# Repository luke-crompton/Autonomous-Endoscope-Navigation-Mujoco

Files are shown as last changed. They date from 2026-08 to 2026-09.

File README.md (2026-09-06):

# Autonomous Colonoscope Navigation

**A reinforcement learning system that drives a flexible endoscope through a colon on its own,
using nothing but the view from its own tip camera.**

> **⚠️ Work in progress.** This is an active research project — the code, results, and
> documentation are all still changing. Treat everything here as provisional, and see
> [docs/CURRENT_PLAN.md](docs/CURRENT_PLAN.md) for where it actually stands right now.

https://github.com/user-attachments/assets/b2985821-82e3-45b8-a4c3-d8f6d5c38c22

*The full closed loop — one episode, ~30 s, no cuts. The trained policy steers itself through a
procedurally generated colon on nothing but what it can see.
**Left:** ground-truth depth, the DA3 depth estimate the policy is actually given, and the error
between them. **Centre:** the tip camera (a Blender render of the colon mesh). **Right:** a
third-person view of the 44-link flexible shaft bending and buckling against the wall as it is
pushed in. Perception runs on a Windows GPU; the policy checkpoint runs in WSL2. Nothing is
privileged and nothing is scripted.*

---

## What this is

Colonoscopy is hard to automate because the scope is a floppy tube: you push at one end and the
tip goes where the anatomy lets it. This project trains a policy to do the whole job in
simulation — steer the articulating tip **and** decide how fast to insert — from a monocular
depth image and a handful of proprioceptive scalars. No trajectory is prescribed and the
policy is never told where the lumen is; it has to infer that from what it can see.

The simulator models the scope as a real physical object: a 44-link flexible shaft fed by an
entrance roller mechanism, with a 25-hinge tendon-driven tip. Push force has to travel around
bends through wall contact, so **buckling, slip and getting stuck are genuine failure modes**
rather than things the model is protected from.

Every design decision is constrained by one rule: **the policy may only observe signals a real
rig can actually supply.** There is no force, tension, motor-current or ground-truth pose
anywhere in the observation.

| | |
|---|---|
| **Sees** | one 54×96 depth image (16:9, 100° horizontal FOV) + 6 scalars — the policy's own previous action, its internal filter state, and a binary tip-contact flag |
| **Does** | 3 continuous outputs in [-1, 1] — two cable-pair bend setpoints and one insertion feed rate |
| **At** | 25 Hz, matching the deployment rate the real depth model can sustain |
| **Trained by** | recurrent PPO (Sample Factory APPO) on procedurally generated colons |

---

## Status

**In real-hardware bring-up.** Simulation work is complete for this phase; the next milestone is
a physical rig trial. Current plan and open questions:
[docs/CURRENT_PLAN.md](docs/CURRENT_PLAN.md).

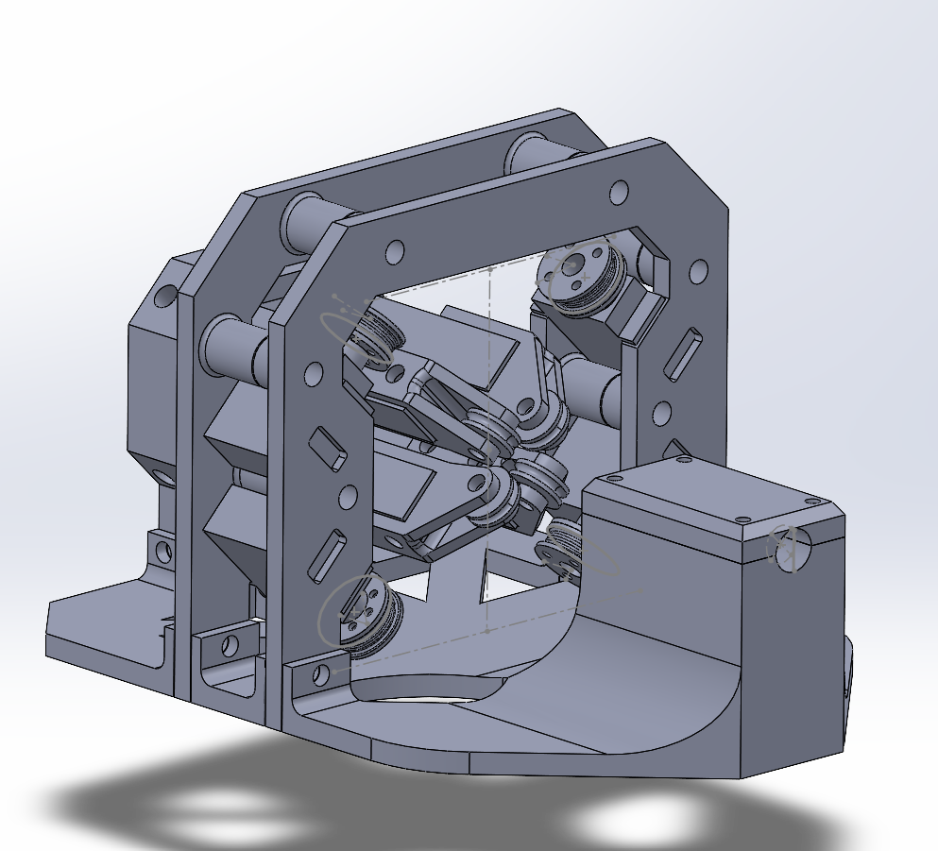
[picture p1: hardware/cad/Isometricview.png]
The tendon drive rig


*The tendon drive rig — four cables to two antagonistic pairs, driven by serial bus servos, with
a cantilever load cell on the shaft axis. [Open it in interactive 3D](hardware/cad/Full%20assem.STL).*

| Result | Value | Evidence |
|---|---|---|
| **v8_p1** (live line — physical shaft, 25 Hz, hardware-matching observation) | ~97% mean progress @ 4.52M steps | ⚠️ *training* statistic from sampled rollouts — **no evaluation run yet** |
| **v6_dr** (frozen milestone — kinematic base advance) | **93.75% completion, 96.7% mean progress** | benchmarked over 80 seeds × 5 episodes, [eval CSV included](navigation/v6_dr/runs_sf/v6_dr_700V3/) |
| Depth model (DA3-SMALL, fine-tuned) | 1.43 mm scale-aligned val MAE, vs 8.30 mm zero-shot | ⚠️ output is **scale-relative, not metric** — this is not a distance accuracy you can obtain at deploy |
| Depth throughput on the real camera | 31 fps / 32.18 ms | measured, `perception/realtime/bench_da3.py` |

The two lines are not directly comparable: v6_dr moved the scope base kinematically, while
v8_p1 has to physically push a flexible shaft. The completion metric also changed on
2026-07-13. **Mean progress is the honest axis** across versions.

---

## Where to go next

| If you want to know… | Read |
|---|---|
| How the whole system fits together | [docs/architecture.md](docs/architecture.md) — the three pipelines, the control loop, the network, the sim-to-real bridge |
| Why it is built this way, and what failed first | [docs/ITERATION_HISTORY.md](docs/ITERATION_HISTORY.md) — v1 → v8_p1, including the dead ends |
| The physical rig and what has to be measured | [hardware/README.md](hardware/README.md) — and [the assembly in interactive 3D](hardware/cad/Full%20assem.STL) |
| What happens next | [docs/CURRENT_PLAN.md](docs/CURRENT_PLAN.md) |
| Which RL version is which | [navigation/README.md](navigation/README.md) |
| How to run any of it | [docs/DEV_SETUP.md](docs/DEV_SETUP.md) |
| Everything else | [docs/README.md](docs/README.md) — full documentation index |

---

## Repository map

| Folder | What it is |
|---|---|
| `navigation/` | The RL system — environment, training, evaluation. Three lines: `v8_p1/` (**live**), `v7_shaft/` (superseded), `v6_dr/` (frozen milestone). See [navigation/README.md](navigation/README.md). |
| `perception/` | Monocular depth. `rd_v2/` is the DA3-SMALL fine-tune pipeline and error-map generator; `realtime/` is the live deployment runtime and camera tooling. |
| `simulation/` | Reference videoscope tip model. The navigation bundles carry their own copies by design. |
| `hardware/` | The physical rig — CAD, firmware, flex-PCB electronics, and bring-up measurements. See [hardware/README.md](hardware/README.md). |
| `docs/` | Documentation, iteration history, and archived training runs. |

Trained checkpoints are **not** in this repository — they exceed GitHub's file size limit and
are distributed as Release assets. `scenes/` folders are generated output and are always
regenerable.

---

## Attribution

The videoscope tip simulation (`generate_videoscope_one_section.py`, `new8.stl`) and the Blender
dataset-generation scripts used for depth fine-tuning were **provided by a research supervisor**,
and `colon_generator.py` is a port of the supervisor's generator. The navigation environment,
collision and contact modelling, reward design, domain randomisation, depth fine-tuning, the
sim-to-real error-map method, and all RL work are the author's own.

Licensed under the MIT License — see [LICENSE](LICENSE).

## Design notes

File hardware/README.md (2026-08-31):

# hardware/ — the physical rig

The real scope, the mechanism that drives it, and the measurements that decide whether the
trained policy transfers. This is where the project is now: simulation work for this phase is
complete and the next milestone is a physical rig trial.

> **⚠️ Work in progress.** The rig is still being built and nothing has been trialled yet.
> Insertion is **hand-fed for now** — the automatic feed drive is not built. The first
> policy-driven tests will run without it: the shaft is pushed in by hand so the **steering
> response** can be checked on its own before the feed mechanism is added.

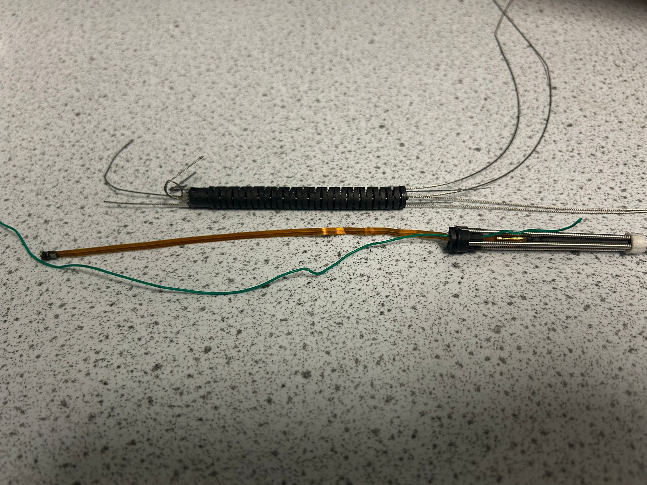
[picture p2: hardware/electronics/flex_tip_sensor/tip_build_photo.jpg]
The scope tip and its internals


*Two stages of the bending tip during assembly. Top: a bare articulating disk stack. Bottom: a
wired tip section — the flat orange ribbon is the camera cable, the four fine cables are the
steering tendons, and the coiled section is the tension spring. (The flex tip-contact sensor is
not fitted in this shot.)*

<table>
<tr>
<td>tip-to-shaft internals</td>
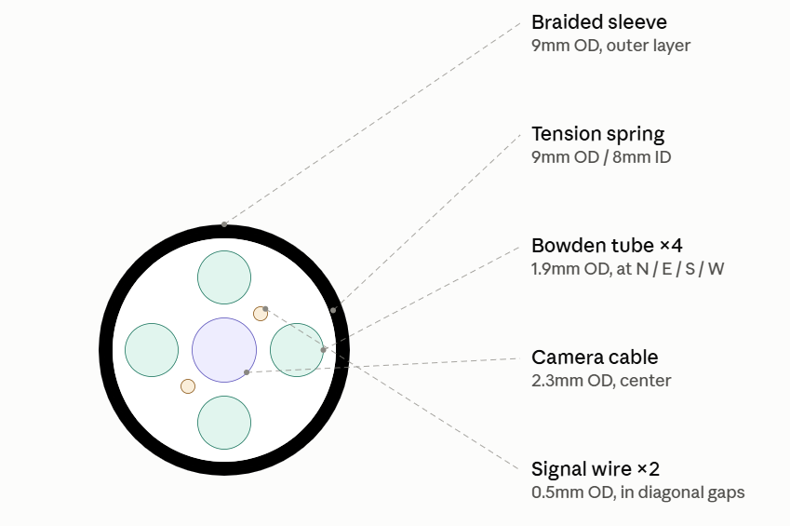
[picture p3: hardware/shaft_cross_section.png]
shaft cross-section
<td></td>
</tr>
</table>

*Left: the tip-to-shaft internals — the full shaft assembly end to end with the flexible spring
and braided housing removed. Right: the shaft cross-section — four tendon Bowden tubes at
N / E / S / W, the camera cable down the centre, and the two flex-sensor signal wires in the
diagonal gaps, all inside a tension spring and a braided sleeve. The tension spring provides a cylindrical shape and compression ridgitiy, and the braided sleeve provides the torsional ridgity to transmit rotation from the base to the tip. From testing the shaft internals provide enough bending resistance to stop buckling whilst still being flexible enough to navigate tight bends*

| Folder | What goes in it |
|---|---|
| [`cad/`](cad/) | SolidWorks sources for the scope, feeder and mounting, plus [`Full assem.STL`](cad/Full%20assem.STL) — **click it on GitHub for an interactive 3D view of the rig** |
| [`firmware/`](firmware/) | Arduino / microcontroller code driving the tendon motors and feed rollers |
| [`electronics/`](electronics/) | Flex PCBs. So far [`flex_tip_sensor/`](electronics/flex_tip_sensor/) — the tip-contact sensor (fabricated, not yet calibrated) |
| [`bringup/`](bringup/) | Test procedures, measurement scripts, and recorded results |

**Live camera and depth tooling is not here** — it lives in `perception/realtime/`
(`probe_camera.py`, `preview_camera_depth.py`, `bench_da3.py`). The dividing line: code that
processes images belongs to `perception/`, code that commands motors or reads encoders belongs
here. Procedures that exercise both go in `bringup/`.

---

## What the rig has to provide

These are requirements the simulator imposes — see [`../docs/architecture.md`](../docs/architecture.md)
for how the loop works, and the constants table at the end of this page for the exact numbers.
Nothing here describes measured hardware behaviour.

| | Requirement |
|---|---|
| **Rate** | one decision per 40 ms (25 Hz) |
| **Camera** | 16:9 frame; the policy was trained on 100° horizontal rectilinear |
| **Tendons** | 4 cables in 2 antagonistic pairs, **pull-only**, position-commanded to an absolute pull in mm |
| **Feed** | signed insertion rate, ±30 mm/s at full command — **hand-fed for now**, so `a[2]` is an operator advance/hold/withdraw cue, not yet a driven axis |
| **Contact** | a binary tip-contact flag — the only exogenous signal in the state vector besides the image. Hardware: [`electronics/flex_tip_sensor/`](electronics/flex_tip_sensor/), fabricated but not yet calibrated |
| **Software state** | the PD command shaper and previous-action echo must be **reproduced in software**, not measured — five of the six state floats are internal, not sensors |

---

## Status

**Not yet trialled.** Bring-up is in progress; see [`bringup/`](bringup/) for the pre-flight
measurements that have to happen before the first policy-driven run, and
[`../docs/CURRENT_PLAN.md`](../docs/CURRENT_PLAN.md) §7 for the authoritative sequencing.

The **tip-contact sensor now exists in hardware** — a polyimide flex electrode with a
piezoresistive film, [`electronics/flex_tip_sensor/`](electronics/flex_tip_sensor/) — but it is
uncalibrated and not yet wired in, so it does not change the status above.

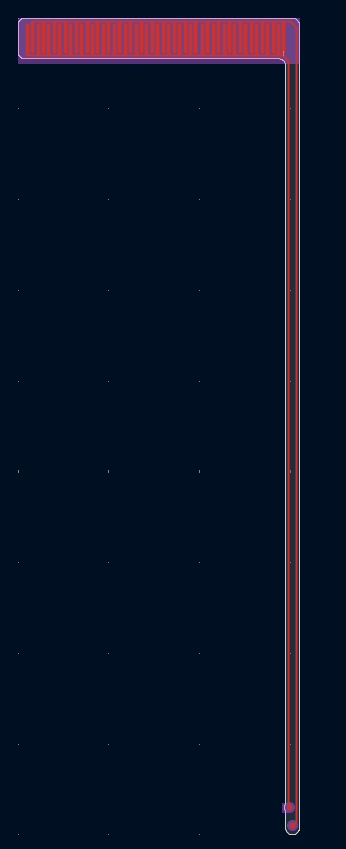
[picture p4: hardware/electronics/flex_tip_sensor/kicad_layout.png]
flex tip-contact sensor PCB layout


*Flex sensor PCB — comb head, 1.5 mm pigtail, solder pads. [Details](electronics/flex_tip_sensor/).*

Three sim-to-real gaps are known and quantified:

1. **Lens distortion.** The real camera is a **122° horizontal fisheye**; the pipeline was built
   on 100° horizontal rectilinear. Fix is perception-side only (measure `K`/`D`, then a
   precomputed `cv2.fisheye` undistort LUT applied before DA3) and is not a retrain blocker.
2. **`MAX_PULL_X` / `MAX_PULL_Z` are sim-derived** (6.795 / 7.361 mm). They normalise two of the
   six live policy inputs, so measuring them on the real scope is a correctness requirement, not
   an improvement.
3. **Camera roll offset is unmeasured.** In sim the tip camera is body-fixed and never rotates,
   so the image↔cable relationship is a constant. On the real scope that constant is unknown.
   The measurement procedure and what to do with the result are in [`bringup/`](bringup/) §2.

---

## Constants the deployment loop must reproduce

Read straight off `navigation/v8_p1/` (which is under version control). For the reward shape,
domain randomisation and episode logic — all training-only — see
[`../docs/architecture.md`](../docs/architecture.md).

| Quantity | Value | Note |
|---|---|---|
| Decision rate | **25 Hz** (40 ms) | 80 MuJoCo substeps × 0.5 ms in sim |
| `depth` observation | `(1, 54, 96)` float32, `[0, 1]` | normalise by **each frame's own maximum**, not a fixed metric clip — the obs is scale-relative |
| Camera field | **100.0° H × 67.7° V**, rectilinear, 16:9 | the sim camera and the DA3 fine-tune camera are the same camera by construction |
| `state` observation | `[cmd_x_n, cmd_y_n, last_action[0..2], tip_contact]` | 5 of 6 are software echo; only `tip_contact` is a sensor |
| `MAX_PULL_X` | 6.795 mm (X pair spans 12 joints) | ⚠️ from sim geometry — **measure on the real scope**, keep X and Z separate |
| `MAX_PULL_Z` | 7.361 mm (Z pair spans 13 joints) | ⚠️ same |
| PD command shaper | `PD_KP = 0.1803`, `PD_KD = 0.0475` | fitted at 25 Hz — **do not arithmetically rescale** for another rate (poles go unstable) |
| PD shaper response | τ = 214 ms, 95% settle 640 ms, 0% overshoot | its output is fed back as obs slots 0–1 — the filter is *inside* the observation loop |
| Action `a[0]`, `a[1]` | absolute pull setpoint `= a × MAX_PULL` | a position command, not a rate |
| Action `a[2]` | feed rate, full scale `1.2 mm/step = 30 mm/s` | accumulates into a monotonic insertion-depth target |
| Tendon force rail | **−10 N, pull-only** | cables cannot push |
| Policy output | take the Gaussian **mean**, not a sample | sampled σ ≈ 0.63; the mean cuts tip-command jitter ~91% |
| GRU hidden state | persists across steps, zeroed only at run start | re-instantiating the network per frame is not the trained policy |

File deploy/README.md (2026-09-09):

# deploy/ — the physical-rig control loop

The runtime stack that drives the real scope: **image → DA3 depth → APPO policy →
tendon setpoints → ESP32-S3**. Training / simulation lives in `navigation/`; this
directory is deployment only.

See `docs/architecture.md` ("The control loop") and `hardware/README.md`
("Constants the deployment loop must reproduce") for the contract, and
`docs/CURRENT_PLAN.md` §7 for where bring-up stands.

## Node graph

```
WINDOWS (no ROS, py3.11)          |  WSL2 UBUNTU (ROS 2 Humble)
camera idx 1 → DA3 → to_obs       |
  (1,54,96) f32, [0,1]            |
        │  TCP (TCP_NODELAY)      |
        └───────────────────────► depth_bridge ──/scope/depth───┐   sensor_msgs/Image 32FC1
                                                                 │
                                   /scope/telemetry ─────────────┤   scope_msgs/ScopeTelemetry
                                   /scope/estop (latched) ───────┤   std_msgs/Bool
                                   /scope/run_state (latched) ───┤   scope_msgs/ScopeRunState
                                                                 ▼
                                                          [ policy_node ]
                                                            APPO + GRU + PD command shaper
                                                                 │
                                                    /scope/action ▼   ScopeAction (normalised -1..1 per pair)
                                                          [ scope_link ] ──serial(COBS)──► ESP32-S3
                                                                 ▲                          runtime firmware
                                                                 └── /scope/telemetry, /scope/estop
```

No fisheye undistort — the 122°/100° lens gap is a known, accepted transfer risk
(`CURRENT_PLAN.md` §8). Insertion is hand-fed, so the policy's feed action never
reaches the motors; `policy_node` consumes it only as observation echo.

The steering command on the wire is **normalised** (±1 = full commanded bend).
The PD shaper runs normalised too — exactly matching the sim's `cmd / MAX_PULL`,
so nothing ROS-side needs `MAX_PULL`. The real per-axis-per-direction encoder
limits are **asymmetric** (measured: x +724/−681, z +840/−603 ticks —
`hardware/bringup/measured_constants.md`) and live only in the firmware, pushed
from `scope_params.yaml` via the `CONFIG` frame.

## Layout

| Path | State |
|---|---|
| `ros2_ws/src/scope_msgs/` | `ScopeAction`, `ScopeTelemetry`, `ScopeRunState`, `ScopeCommand` — **done** |
| `ros2_ws/src/scope_control/scope_control/policy_node.py` | inference + PD shaper + obs assembly — **done** |
| `ros2_ws/src/scope_control/scope_control/policy_runner.py` | SF-checkpoint wrapper (`reset()` / `act()`) — **done** |
| `ros2_ws/src/scope_control/scope_control/depth_bridge.py` | Windows TCP depth → `/scope/depth` — **done** |
| `ros2_ws/src/scope_control/scope_control/scope_link.py` | serial (COBS) ↔ ESP32-S3, derives `/scope/estop` — **done** |
| `ros2_ws/src/scope_control/scope_control/scope_link_proto.py` | canonical serial protocol (COBS + CRC-16) — **done** |
| `ros2_ws/src/scope_control/scope_control/mock_scope_link.py` | bench MCU stand-in for `policy_node` tests — **done** |
| `ros2_ws/src/scope_control/scope_control/fake_depth_pub.py` | synthetic `/scope/depth` for bench tests — **done** |
| `ros2_ws/src/scope_control/launch/bench.launch.py` | mock graph (mock policy + mock MCU) — **done** |
| `ros2_ws/src/scope_control/launch/rig.launch.py` | real graph (depth_bridge + policy_node + scope_link) — **done** |
| `ros2_ws/src/scope_control/config/scope_params.yaml` | the loop's constants — **done** |
| `win_vision/win_vision_server.py` | camera → DA3 → TCP (Windows, py3.11) — **done** |
| `tools/mock_firmware.py` | fake ESP32-S3 over a serial pty, for `scope_link` tests — **done** |
| `../hardware/firmware/scope_control_s3/` | ESP32-S3 runtime firmware (normalised→ticks, SYNC-WRITE pairs, safety governor, e-stop) — **done, not compile-tested here** |

**Whole loop is now drafted.** Remaining before a rig trial is calibration +
verification, not new code: verify `AXIS_SERVO` / `AXIS_INVERT` (which pair is X
vs Z, steering sign) by driving the tip; wire the e-stop MOSFET + tip sensor;
bench-measure `CURRENT_LSB_MA`; verify `PolicyRunner.act()` against
`viewer_sf.py --deterministic` to 1e-6. `MAX_PULL` is measured
(`scope_params.yaml`).

### Depth wire protocol (win_vision → depth_bridge)

TCP, `TCP_NODELAY`. One frame = 20-byte header + payload:

```
struct "<4sHHIQ" :  magic b"SDP1" | uint16 height | uint16 width | uint32 seq | uint64 sender_t_ns
payload          :  height*width*4 bytes, float32 little-endian, row-major, already [0,1]
```

`depth_bridge` validates `height×width` against `expected_*` params (drops with a
loud error on mismatch — `win_vision` owns the resize) and republishes as
`sensor_msgs/Image` `32FC1`.

### Serial protocol (scope_link ↔ ESP32-S3)

Canonical definition + a COBS/CRC-16 codec in `scope_link_proto.py` (`PROTO_VERSION 2`);
the firmware mirrors it in C++. Frames are `COBS(type | payload | crc16)` + `0x00`.
Host→MCU: `SETPOINT` (cmd_x_n, cmd_y_n ∈ [-1,1] + seq), `CONFIG` (safety limits +
rates + the 4 asymmetric MAX_PULL tick limits + headroom),
`COMMAND` (ENABLE/DISABLE/CLEAR_SAFETY/ESTOP), `PING`.
MCU→Host: `TELEMETRY` (seq echo, flags, tension[4], pos[4], current[4]),
`LOG`, `PONG`, `HELLO` (applied MAX_PULL + zeros).
`/scope/estop` is asserted by `scope_link` whenever the link is down, the
firmware reports ESTOP, or an operator ESTOP is outstanding.

## Build & run (WSL2)

```bash
cd deploy/ros2_ws
colcon build --packages-select scope_msgs scope_control
source install/setup.bash

# --- bench: whole graph, no rig, no checkpoint ---
ros2 launch scope_control bench.launch.py
ros2 run scope_control fake_depth_pub --ros-args -r __ns:=/scope
ros2 topic pub -1 /scope/run_state scope_msgs/msg/ScopeRunState '{command: 2}'   # RESET+RUN
ros2 topic hz /scope/action                                                     # expect ~25 Hz

# --- bench: exercise the real scope_link against a fake firmware ---
socat -d -d pty,raw,echo=0 pty,raw,echo=0          # note the two /dev/pts/N it prints
python ../tools/mock_firmware.py --port /dev/pts/B --spike-after 10
ros2 run scope_control scope_link --ros-args -r __ns:=/scope \
  --params-file src/scope_control/config/scope_params.yaml -p port:=/dev/pts/A
ros2 topic pub -1 /scope/command scope_msgs/msg/ScopeCommand '{command: 1}'      # ENABLE
#   -> /scope/telemetry flows; after 10 s the mock trips -> /scope/estop true

# --- rig: real inference + real serial ---
#   edit config/scope_params.yaml (nav_code_dir, checkpoint_root, port) first
ros2 launch scope_control rig.launch.py port:=/dev/ttyUSB0
#   then on Windows:  py -3.11 deploy/win_vision/win_vision_server.py --host <WSL_IP>
ros2 topic pub -1 /scope/command   scope_msgs/msg/ScopeCommand  '{command: 1}'   # ENABLE firmware
ros2 topic pub -1 /scope/run_state scope_msgs/msg/ScopeRunState '{command: 2}'   # RESET+RUN policy
```

## The one rule

`policy_node` reproduces the simulator's PD command shaper and previous-action
echo **exactly** — they are policy *inputs*, not just outputs. `pd_kp` / `pd_kd`
were fitted at 25 Hz and are not arithmetically rescalable. The GRU hidden state
is load-bearing and is zeroed only on `RESET`.

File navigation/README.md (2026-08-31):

# navigation/ — RL navigation lines

| Folder | Status | Result |
|---|---|---|
| `v8_p1/` | **LIVE** — all new work happens here | `v8_p1_v1`, A–F retrain (2026-08-04, from scratch, stopped at 4.52M steps): **~97% mean progress** — a *training* statistic from sampled rollouts, **no eval run yet**. Supersedes the post-0713 run (93.5% mean progress, `tip_stuck` 73.3% → 12.3%). See [../docs/CURRENT_PLAN.md](../docs/CURRENT_PLAN.md). |
| `v7_shaft/` | **SUPERSEDED** by `v8_p1/` — kept runnable, don't develop here | v7_shaft_v2: ~92% mean progress / ~90% completion. v7_shaft_v4 evaluated at 35.0% completion / 72.3% mean progress, but on a colon generator with a self-intersection bug fixed the same day — not a clean read. |
| `v6_dr/` | **FROZEN milestone** — eval/view only, do not edit | v6_dr_700V3: 93.75% completion / 96.7% mean progress over 80 seeds × 5 episodes (eval CSV in `runs_sf/v6_dr_700V3/`). Last version with the kinematic mocap base advance. |

v7_shaft replaced v6's kinematic base with a real physical flexible shaft (two-DOF universal
joints) fed by an entrance roller/capstan mechanism — wall contact transmits push force around
bends, and slip/buckling are genuine failure modes, as in real colonoscopy.

**v8_p1** ("V8 Phase 1" — the folder is `v8_p1/`, *not* `v8/`, which never existed) then replaced
the privileged force observations with a hardware-matching **cable-extension** signal, added tendon
integral control, and reworked shaft/tip compliance. The 2026-08-04 A–F retrain went further:
the state is now **6-D with no force or cable channel at all** (`force_norm`, `net_fx`/`net_fz`,
and finally `ten_x_n`/`ten_z_n` all lack a faithful real-hardware equivalent), tendon force was cut
~9× to a bench-measured ~3 N, the tip camera moved to a 16:9 100°-horizontal frame, and the control
loop dropped to 25 Hz to match the deployment rate. Full lineage and design rationale:
[../docs/ITERATION_HISTORY.md](../docs/ITERATION_HISTORY.md).

All three folders are deliberately self-contained bundles (each carries its own
`generate_videoscope_one_section.py`, `new8.stl`, `error_map_64.npy`): the frozen v6 snapshot
stays runnable with zero edits, and the live `v8_p1/` folder syncs to the Linux training rig and
the WSL2 mirror as a single unit. **Never add cross-folder imports.**

**Phase 2** (gravity + anatomical left-lateral-decubitus colon) is unstarted and has no folder.
Per the original design it would target `v8_p1/` in place rather than forking a new line.

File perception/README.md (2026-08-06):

# perception/ — monocular depth

The policy's only view of the world is a depth image. This folder produces the model that
generates it, and the runtime that runs it on the real scope.

| Folder | Role | Runs |
|---|---|---|
| `rd_v2/` | **Offline pipeline.** Fine-tunes DA3-SMALL on rendered colon imagery and measures its error. Run once; produces two artefacts the rest of the project consumes. | Blender + CUDA, hours |
| `realtime/` | **Deployment runtime.** The live inference path, camera tooling, and latency benchmark. | live camera, 31 fps |

Both require **Python 3.11**, not the 3.14 used for `navigation/` — the CUDA torch,
`depth_anything_3` and OpenCV stack exists only there. `realtime/_py311.py` relaunches a script
under the right interpreter automatically; otherwise invoke as `py -3.11`.

---

## What it produces

| Artefact | Consumed by |
|---|---|
| `da3small_finetune_head.pth` | the deployment runtime — **131 MB, not in git**, distributed as a Release asset |
| `error_map_64.npy` | the RL environment, copied into each `navigation/` bundle — the sim-to-real bridge |

The error map is the project's main sim-to-real idea: rather than injecting generic noise into
simulated depth, it injects *the measured spatial error structure of the actual deployment
model*. See [../docs/architecture.md](../docs/architecture.md).

## ⚠️ The depth is relative, not metric

`metric_weight = 0`, so the model's output is **scale-relative**. The headline **1.43 mm val
MAE** (against 8.30 mm zero-shot) is *scale-aligned against ground truth* — it is not a distance
accuracy obtainable at deploy time, and millimetres must never be read off the output. Older
documents quoting **1.60 mm** are wrong; the checkpoint log is authoritative.

This is consistent with how the RL side uses it: the environment normalises each depth frame by
its own maximum, so the policy reads relative structure and never has access to absolute
distance.

---

## `rd_v2/` — the offline pipeline

```
blender_depth_dataset.py       →  training frames (Blender/Cycles, OPTIX)
filter_void_frames.py          →  drops frames with too many pure-black pixels
finetune_da3.py                →  da3small_finetune_head.pth   (head-only; backbone frozen)

blender_depth_dataset_eval.py  →  unseen eval frames, different geometry
run_da3_inference.py           →  predictions
compute_error_map.py           →  error_map_64.npy
```

`generate_error_map.py` runs that whole chain end to end — it needs Blender and takes hours.
`test_navigation.py` closes the loop offline, driving the MuJoCo scope with the fine-tuned model
as its perception. `error_map_48.npy` and `error_map_full.npy` are alternate resolutions;
**`error_map_64.npy` is the one in use**.

## `realtime/` — the deployment runtime

| Script | |
|---|---|
| `da3_runtime.py` | **the single shared inference path.** Reproduces the fine-tune contract exactly (504×280, ImageNet normalisation) and provides `to_obs_64()` for the navigation observation |
| `bench_da3.py` | latency benchmark — **31 fps / 32.18 ms measured**, which is why the control loop is 25 Hz |
| `probe_camera.py` | reports what the camera *actually* delivers, as opposed to what it claims |
| `preview_camera_depth.py` | live camera → depth preview, for eyeballing output and frame rate |

The scope camera is **OpenCV index 1**. Index 2 is a broken NVIDIA Broadcast virtual device —
opening it wastes time.

---

## Known gaps

- **Lens distortion.** The real camera is a **122° horizontal fisheye**; the pipeline was built
  on **100° horizontal rectilinear**. The fix is perception-side only — measure `K`/`D`, then a
  precomputed `cv2.fisheye` undistort LUT applied before DA3 — and it does not require a
  retrain. This is the largest known observation mismatch.
- **The error map's geometry is approximate.** It was measured on the older square 85° camera
  and is resized to the current 54×96 frame, an anisotropic stretch. It is a smooth envelope, so
  this is a mild distortion rather than a wrong signal — but it is not a verified map at the
  current geometry.

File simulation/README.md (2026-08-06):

# Videoscope Simulations

One-section MuJoCo videoscope model with manual tendon pulling.

## Model

- 25 hinge joints
- 26 disks
- 9.0 mm outer diameter
- 4 tendon holes at 0, 90, 180, and 270 degrees
- Tendon holes are 3.2 mm from the central origin
- Ball/socket rotation diameter is 2.0 mm
- Adjacent disk centers are 2.5 mm apart
- The distance from each joint center to the top of its disk is 2.5 mm
- `new8.stl` is rotated by 90 degrees on alternating disks about the long axis
- The next joint is placed at the top of the previous disk to keep the joint
  interface visually closed during bending
- No joystick and no automated trajectory

## Files

- `generate_videoscope_one_section.py` builds the XML.
- `videoscope_one_section.xml` is the MuJoCo model.
- `manual_tendon_viewer.py` launches the viewer and leaves tendon sliders manual.
- `new8.stl` is overlaid as the visual mesh for each joint disk.

## Requirements

- Python 3.10 or newer
- MuJoCo Python package

Install MuJoCo with:

```bash
python -m pip install mujoco
```

On some systems the command may be `python3` instead of `python`.

## Run The Simulation

Open a terminal in this folder, then run:

```bash
python generate_videoscope_one_section.py
python manual_tendon_viewer.py
```

If your system uses `python3`, run:

```bash
python3 generate_videoscope_one_section.py
python3 manual_tendon_viewer.py
```

The first command regenerates `videoscope_one_section.xml`. The second command
opens the MuJoCo viewer.

## Manual Tendon Controls

Use the MuJoCo viewer Controls panel. The viewer script enforces antagonistic
tendon pairs:

- X pair: `pull_px` and `pull_nx`
- Z pair: `pull_pz` and `pull_nz`

Pulling one side releases the opposite side by the same amount. Slider units
are metres. For example, `0.003` is 3 mm of tendon pull and `-0.003` is 3 mm
of tendon release. The maximum pair command is `+/-0.024`, which is 24 mm.

## Notes

- There is no joystick control.
- There is no automated movement sequence.
- The visual geometry uses `new8.stl`; keep that STL in the same folder as the
  XML and Python scripts.
- The hidden simple cylinder geometry is used only to keep the simulation
  stable; the STL remains the visible disk shape.

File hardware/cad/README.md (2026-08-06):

# hardware/cad/

The physical rig: tendon drive, spools, shaft clamp and cantilever force mount. Roughly
180 × 130 × 110 mm.

**[▶ View the assembly in 3D](Full%20assem.STL)** — GitHub renders it interactively; rotate and
zoom in the browser, no software needed.

Isometric view of the rig

## Cable routing

Each tendon leaves its spool, turns over a pulley, and runs forward into the shaft clamp on the
scope axis. **The green lines are the drawn cable paths** — construction geometry, not parts.

| | |
|---|---|
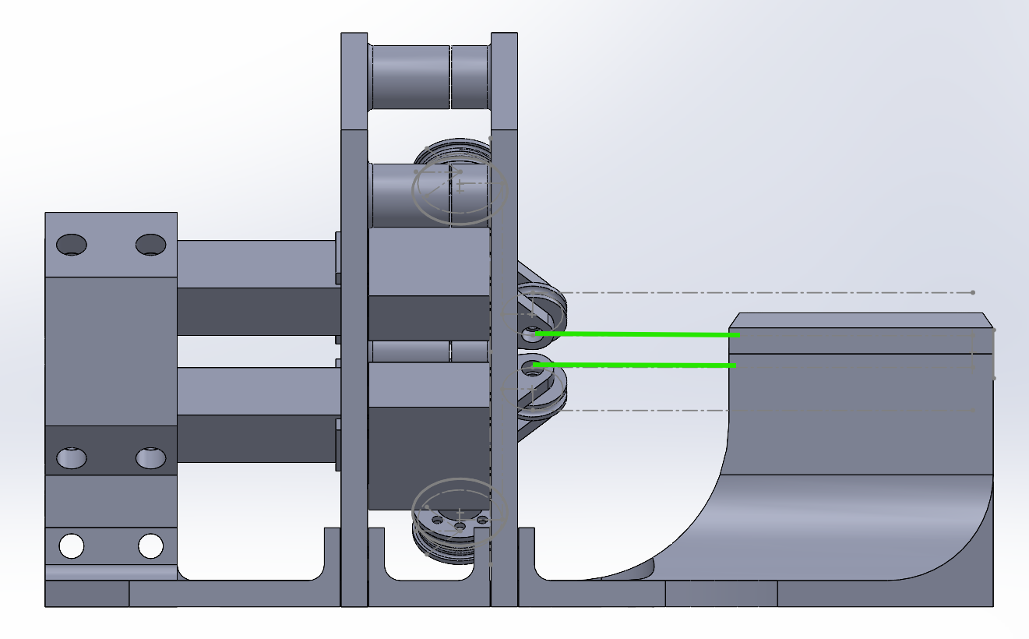
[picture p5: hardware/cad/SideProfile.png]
Side profile
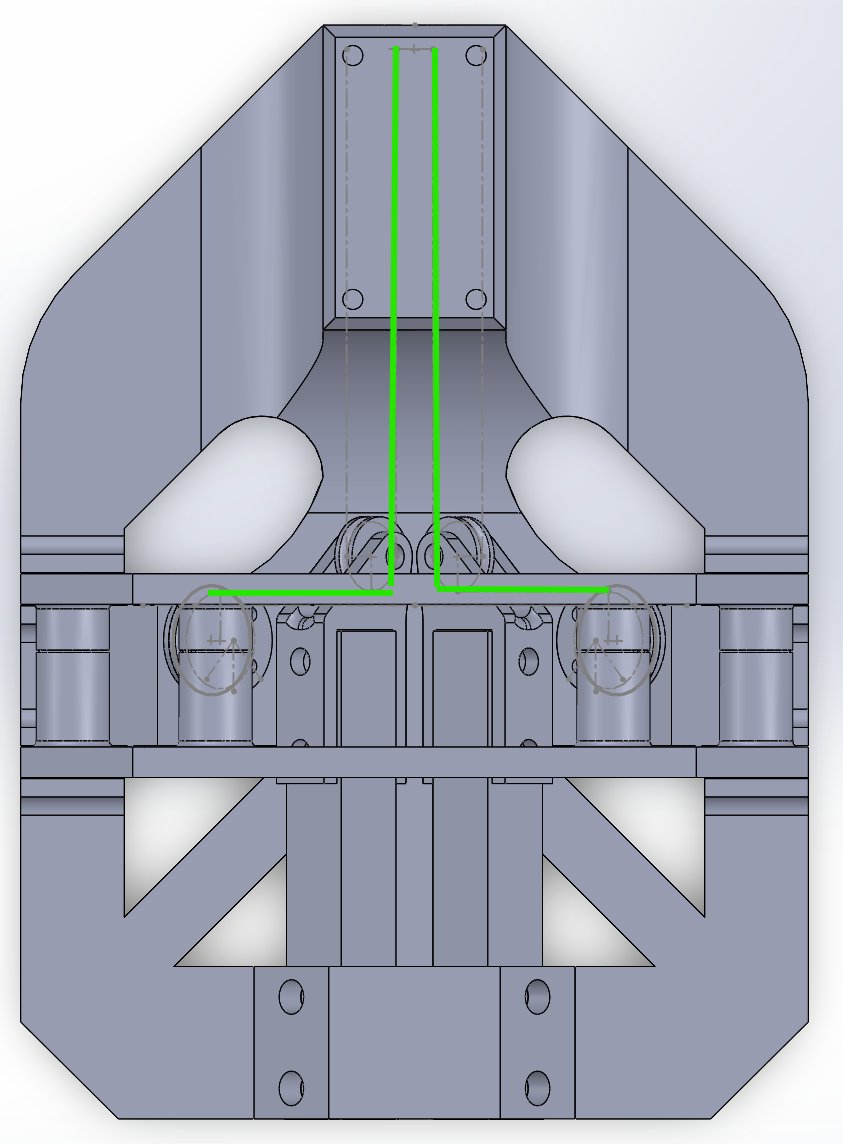
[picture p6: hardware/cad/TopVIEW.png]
Top view
|  |  |
| **Side** — cables leave the pulleys and run horizontally into the clamp | **Top** — the pair turns through 90° over the pulleys and into the shaft channel |

## Shaft clamp

The clamp at the scope end is designed for a **9–10 mm OD shaft** carrying **four antagonistic
tendon cables** — the same arrangement the simulated scope uses, so the drive geometry here and
the tendon model in `navigation/` describe the same mechanism.

## Bought-in components

Three parts here are **off-the-shelf, not my design.** They are included because the surrounding
parts were designed around them — their mounting patterns, envelopes and load paths set the
geometry of everything they touch:

| Part | What it is | Designed around it |
|---|---|---|
| `sts3032.SLDPRT` | STS3032 serial bus servo | `sts3032 Bracket male` / `Bracket Female`, the mounting pair that carries it |
| `Load cell block.SLDPRT` | cantilever force bar (load cell) | `Cantilever bracket`, which fixes it and sets the measuring axis |
| `bearing wheel.SLDPRT` | bearing | the pulley and spool assemblies that run on it |

Everything else is my own: the spool, pulley, shaft clamp and clamp top.

## Files

| File | |
|---|---|
| `Full assem.SLDASM` | the complete assembly |
| `Layout Assembely.SLDASM` | layout assembly, shares parts with the above |
| `Full assem.STL` | merged mesh of the whole rig — for viewing, not for printing |
| 10 × `.SLDPRT` | the individual parts |

Flat folder by design: SolidWorks resolves references between files in the same directory with
no path rewriting, so the assembly opens correctly straight from here.

Print-ready geometry is not kept here — open the assembly and export what you need.

---

*Working copy lives outside the repo; see [DEV_SETUP.md](../../docs/DEV_SETUP.md) for how this
folder is refreshed after a design change.*

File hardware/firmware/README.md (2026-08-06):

# hardware/firmware/

Microcontroller code driving the tendon motors and feed rollers. **Empty as of 2026-08-06.**

## What this layer is responsible for

The policy emits three numbers in [-1, 1] at 25 Hz. Everything between those numbers and the
motors is firmware's problem:

| Policy output | Meaning | What firmware must do |
|---|---|---|
| `a[0]` | X-axis bend **setpoint** | drive the X cable pair to an absolute pull in mm — one cable pulls, the opposing one releases by the same amount |
| `a[1]` | Z-axis bend **setpoint** | same, on the other pair |
| `a[2]` | insertion **rate**, signed | accumulate into a monotonic depth target and drive the feed rollers |

`a[0]` and `a[1]` are **absolute positions, not rates.** `a[2]` *is* a rate. Getting this
backwards produces a scope that appears to work and steers nothing.

## Three things that will silently break the policy

1. **Cables pull only.** In sim the tendon force rail is `[-10, 0] N` — a cable can never push.
   Any implementation where a "negative pull" drives the cable outward is not the trained
   system.
2. **The PD command shaper is not firmware's to invent.** It sits *inside* the observation loop:
   its output is fed back as two of the six policy inputs. It must be reproduced exactly, with
   the same gains, at the same rate, on whichever side of the wire runs the policy — and its
   gains **do not rescale arithmetically with rate**. See
   [`../../docs/architecture.md`](../../docs/architecture.md).
3. **`MAX_PULL_X` and `MAX_PULL_Z` differ** (6.795 vs 7.361 mm in sim, because the axes span 12
   vs 13 joints), and both are **sim-derived numbers pending measurement on the real scope**.
   They normalise live policy inputs, so a wrong value is not a scaling nuisance — it feeds the
   network the wrong observation.

## What firmware must report back

Only one thing the policy actually consumes: a **binary tip-contact flag**. Everything else in
the state vector is software state reproduced on the policy side, not measured.

Encoder feedback is still needed for the motors' own closed loops, and for the pre-flight
`MAX_PULL` measurement — but tendon length is deliberately **not** a policy input. See
`architecture.md` § "What is deliberately not observed" for why that was removed rather than
kept.

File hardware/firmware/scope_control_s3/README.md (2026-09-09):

# scope_control_s3 — runtime control firmware

The **deployment** firmware for the rig ESP32-S3. Not interactive, not a
calibration tool — it is one half of the control loop:

```
scope_link (WSL ROS node)  <—UART 921600, COBS+CRC16—>  scope_control_s3
   /scope/action  → SETPOINT → [ mm → encoder ticks, SYNC WRITE the pairs ]
   /scope/command → ENABLE / DISABLE / CLEAR_SAFETY / ESTOP
                  ← TELEMETRY @ 50 Hz (seq echo, tip_contact, tension, pos, current, safety)
```

The protocol is defined once in
`deploy/ros2_ws/src/scope_control/scope_control/scope_link_proto.py` — this
sketch mirrors it in C++. Bump `PROTO_VERSION` in both on any change.

## What it does

| Concern | Behaviour |
|---|---|
| Setpoint → motion | normalised `cmd_x/y_n` ∈ [−1,1] → per-servo goal ticks via the **asymmetric per-direction MAX_PULL** limits, `PULL_SIGN`, `ZERO_TICK=2048`. Each antagonistic pair moved **equal-and-opposite in one SYNC WRITE** so the two servos start together. |
| Rate | servo goals streamed at `motor_hz` (200); firmware-side slew clamp `MAX_TICKS_PER_CYCLE` bounds tip speed regardless of what's commanded. |
| Safety governor | per-servo current (fast, from the bus) and per-cable tension (HX711) — over a configurable limit for `spike_debounce_ms` → **SAFE_HOLD** (freeze goals, keep torque). |
| E-stop | `ESTOP` command or a critical fault → `ESTOP_MOSFET_PIN` cuts the servo supply. Latching; `CLEAR_SAFETY` re-energises and returns to SAFE_HOLD. |
| Comms watchdog | no SETPOINT for `comms_timeout_ms` → SAFE_HOLD (auto-recovers when frames resume, if still ENABLEd). A safety trip needs an explicit `CLEAR_SAFETY`. |
| tip_contact | ADC threshold on the flex sensor; **forced to 0** until the sensor is wired (`TIP_CONTACT_FORCE_ZERO`). |

Boot state is **SAFE_HOLD** — servos hold their present position, setpoints are
ignored until `/scope/command` `ENABLE`.

## Board / upload

- Board **"ESP32S3 Dev Module"**, **USB CDC On Boot = Disabled** (so `Serial` is
  the CP2102 UART jack = the scope_link link).
- **Flash via the NATIVE-USB jack**; leave the CP2102 jack forwarded to WSL
  (`usbipd`) for the protocol.
- No serial monitor during runtime — output is binary framed. Human-readable
  events come out as `T_LOG` frames and surface in the `scope_link` ROS log.

## Before it can drive the real scope — set these (all marked TODO in the file)

| Constant | Source |
|---|---|
| `AXIS_SERVO`, `AXIS_INVERT` | which pair is cmd_x vs cmd_y, and steering sign — watch the camera image and flip |
| `ESTOP_MOSFET_PIN`, `ESTOP_ENABLE_LEVEL` | the actual e-stop switch wiring |
| `CURRENT_LSB_MA` | STS3032 REG 69 scale (bench-measure against a known load) |
| `TIP_CONTACT_PIN` + threshold, `TIP_CONTACT_FORCE_ZERO` | once the flex sensor is fitted |
| `HX_RATE_PIN` | set if you wire HX711 RATE high for 80 SPS (else tension is ~10 Hz) |

`MAXPULL_DEFAULT` is the measured `bend` result (x +724/−681, z +840/−603 ticks,
2026-09-09) — `scope_link` overrides it at runtime from `scope_params.yaml`
(`maxpull_*_ticks`, `maxpull_headroom`), so it need not be exact.

## Testing without hardware

`deploy/tools/mock_firmware.py` is the inverse of this sketch — it lets you test
`scope_link` with no ESP32. To test *this* sketch, flash it and drive it from
`scope_link` (or a scratch Python client using `scope_link_proto`).

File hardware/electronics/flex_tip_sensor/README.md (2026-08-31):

# hardware/electronics/flex_tip_sensor/

The flexible printed circuit that supplies the policy's one non-visual input: **`tip_contact`**,
a binary "the tip is touching the wall" flag. It is the only exogenous scalar in the 6-D state
vector — the other five are software state reproduced on the policy side, not sensors (see
[`../../README.md`](../../README.md) and [`../../../docs/CURRENT_PLAN.md`](../../../docs/CURRENT_PLAN.md) §2).

**Status: work in progress.** The board has been fabricated. It is **not yet calibrated,
characterised, or wired to the rig** — no resistance threshold set, no bench data, no integration.
Treat the geometry and construction below as settled and everything about its electrical
behaviour as open. `docs/PROGRESS_REPORT_2026-07-14.md` still lists this sensor as unbuilt; that
is the only thing now out of date there.

the flex sensor alongside the articulating tip

*The orange flex sensor — comb head at the left end, pigtail and green hook-up wires trailing off
— next to a bare articulating tip stack (top) and a tip section with its tendon cables and camera
wiring in place (right). This is the build stage before the sensor is bonded and the spring and
braided housing go on.*

KiCad layout of the flex sensor

*KiCad layout, to scale: the comb head (top) and the 1.5 mm pigtail running down to the two
solder pads.*

## What it is

A single-layer polyimide flex circuit in two parts:

| Part | Size | Function |
|---|---|---|
| **Head** | ~31 × 4.5 mm | An interdigitated copper comb — two interleaved electrodes, ~0.6 mm pitch, ~29 mm wide — ENIG-finished and left bare. Wraps **once around the 9 mm-OD tip disk**, the disk that also carries the camera (`disk_25` in the sim tip model). |
| **Pigtail** | 1.5 mm × ~84 mm | Polyimide ribbon carrying the two electrode traces back through the endoscope working channel to two exposed wire-solder pads (`TP1`, `TP2`) with a local stiffener. Kept as slim as possible — no stiffener along its length. |

**How it senses contact:** a piezoresistive film is bonded over the comb. Pressing the film
across the interleaved fingers lowers the resistance between the two electrodes; a threshold on
that resistance becomes the binary flag. **The copper forms no connection on its own** — which is
why there is no meaningful schematic, and why DRC "unconnected" warnings on the comb fingers are
expected (and excluded in the design file). `flex tip sensor.kicad_sch` is a stub holding only
the two solder-pad test points.

## Construction

- Polyimide substrate, 18 µm (½ oz) copper, polyimide coverlay both faces — **except** the comb
  (bare ENIG) and the solder pads (bare).
- Local flexible polyimide stiffener bonded under the solder-pad area only, to protect the wire
  joint from handling stress.
- ~0.1 mm total thickness. Minimum bend radius in service **4.5 mm, static** — the head is
  wrapped once around the tip disk, not repeatedly flexed.
- The KiCad file carries two copper layers only because KiCad requires an even count; `B.Cu` is
  empty and excluded from the Gerbers. **The manufactured part is single-layer.**
- Full fabrication notes are on the board's `Cmts.User` text layer — open it in KiCad, or read
  `Gerbers/flex tip sensor-User_Comments.gbr`.

## Files

| | |
|---|---|
| `flex tip sensor.kicad_pcb` | the layout — open this |
| `flex tip sensor.kicad_pro` | KiCad 10 project |
| `flex tip sensor.kicad_sch` | stub (two test points); kept only so the project opens cleanly |
| `Gerbers/` | fabrication output — `F_Cu`, `F_Mask`, `Edge_Cuts`, `User_Comments`, job file |

Designed in KiCad 10.0.4, 2026-07-21.

## Sim-to-real note

The simulator resolves `tip_contact` as *any* contact between the camera disk and the colon wall
— the cylindrical side face and both flat end faces. **This sensor covers the side face only**,
so a head-on jam is invisible to it. That gap is reviewed and accepted, with reasons, in
[`../../../docs/CURRENT_PLAN.md`](../../../docs/CURRENT_PLAN.md) §2. Setting the film threshold and
checking coverage against that assumption is a [`../../bringup/`](../../bringup/) task once the
sensor is live.

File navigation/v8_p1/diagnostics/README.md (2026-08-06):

# v8_p1/diagnostics/ — physics verification harness

Headless checks for the tendon/shaft/depth model. Written 2026-08-02 to verify Changes A, B and D
in [`docs/CURRENT_PLAN.md`](../../../docs/CURRENT_PLAN.md); kept because the equivalent 2026-07-12
diagnostics were written to a scratchpad and lost, and had to be rebuilt from scratch.

**These are headless and safe to script.** `manual_test.py` (one level up) is *not* — it opens a
MuJoCo viewer and waits for keypresses, so it never exits. Use these for automated verification.

Paths are resolved relative to this file, so they run unchanged on Windows, the Linux training
rig, and the WSL2 mirror. On Windows every script builds the model inside a **64 MB-stack thread**
— MuJoCo's recursive-descent XML compiler blows the default 1 MB stack on the 26-deep `<body>`
nesting and dies with a bare exit-127 and no traceback.

```powershell
# Windows
C:\Python314\python.exe navigation\v8_p1\diagnostics\tendon_force_diag.py --axis x --seconds 5
```
```bash
# WSL2 mirror / rig
~/mujoco_v3/.venv/bin/python navigation/v8_p1/diagnostics/tendon_force_diag.py --axis x
```

## The scripts

| Script | Tests | What it answers |
|---|---|---|
| `tendon_force_diag.py` | **A0 / A1 / A2** | How much cable tension holds full bend, what % of nominal is reached, and whether the joint chain drifts into an S-fold. Free-space tip only, no shaft or colon. `--drift` applies the A2 pass/fail. |
| `tendon_4way_diag.py` | **A3** | Both axes at once through the env's real antagonistic mapping: antagonist fighting, anti-windup behaviour, and `ACTUATOR_KI` overshoot/oscillation. `--pd` ramps via the env's outer PD shaper (what training actually does) rather than a step. |
| `depth_decimation_diag.py` | **B1 / B2 / C1** | That fresh depth frames land 1-in-`DEPTH_DECIMATION`, that the phase varies per episode, that held frames are bit-identical, and a throughput/`ncon` A/B of decimated vs every-step rendering. |
| `shaft_damping_ab.py` | **D1** | `SHAFT_DAMPING` A/B on the full scene with identical seeds *and* identical actions: NaN, velocity blow-up, contact chatter, throughput. |
| `pd_rate_rescale.py` | **F1** | Re-derives `PD_KP`/`PD_KD` for a new control rate by fitting the **wall-clock** step response, since these are the only rate-dependent constants that do not rescale by arithmetic. Reports poles, time constant, overshoot, and hard-reversal slew. No MuJoCo — runs in milliseconds. `--rate 50` for other rates. |

All read their constants live from the modules, so they stay valid after further edits.

## Results on the shipped configuration (2026-08-02)

| Test | Result |
|---|---|
| A0 (pre-change baseline) | 26.57 N to hold full bend — confirmed the 9×-too-stiff diagnosis |
| A1 | **2.92 N** @ 100% of nominal, both axes (bench target ~3 N) |
| A2 | 0.000° joint spread over 40 sim-seconds, no fold |
| A3 | slack tendons 0.000 N; 0.000° overshoot; anti-windup never trips under the PD shaper |
| B1 / B2 | steady-state gap exactly 4; phase varies; longest identical hold run 3 (= D−1) |
| C1 | 1.00× — **rendering is not the bottleneck**, contacts are (`ncon` mean ~54) |
| D1 | NaN 0; peak velocity *lower* than before; throughput 0.96× |
| F1 (2026-08-04) | `PD_KP` 0.06 → **0.1803**, `PD_KD` 0.30 → **0.0475** at 25 Hz. Time constant 214.0 ms preserved to −0.0%; zero overshoot; trajectory RMS 0.0005 mm. A naive ×4 of both gains gives \|z\| = 1.337 — **unstable** |

## Adding a check

Keep it headless, read constants from the modules rather than duplicating them, build inside the
64 MB-stack thread, and record the pass condition in the table above and in `CURRENT_PLAN.md` §6.
A diagnostic whose expected value lives only in a chat log is one that gets rewritten later.

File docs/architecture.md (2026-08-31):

# System architecture

How the whole thing fits together, at the level of "what talks to what and why". For the exact
constants a hardware implementation must match, see
[../hardware/README.md](../hardware/README.md). For *why* it ended up this shape, see
[ITERATION_HISTORY.md](ITERATION_HISTORY.md).

**This describes the `v8_p1` line**, the live one. `v7_shaft/` and `v6_dr/` are earlier
generations kept runnable; `navigation/README.md` says which is which.

---

## The three pipelines

Three pipelines were developed independently and meet at two artefacts: a **depth model** and a
**spatial error map**.

### 1. Perception — run once, offline

Produces the depth model used at deployment, and the error map used during training.

```
blender_depth_dataset.py      →  1,500 Blender RGB + depth pairs
        ↓
filter_void_frames.py         →  cleaned training set (drops black-pixel frames)
        ↓
finetune_da3.py               →  da3small_finetune_head.pth
                                 (head-only fine-tune of DA3-SMALL; backbone frozen)

blender_depth_dataset_eval.py →  500 unseen pairs, different geometry
        ↓
run_da3_inference.py          →  predictions
        ↓
compute_error_map.py          →  error_map_64.npy      ← the sim-to-real bridge
```

### 2. Reinforcement learning — consumes the error map

```
colon_generator.py         →  procedural colon, visual + collision STL
        ↓
build_collision_scene.py   →  assembled MuJoCo scene XML  (never cached — always regenerated)
        ↓
scope_colon_env.py         →  Gymnasium env, 25 Hz decisions
                              · renders 54×96 depth from the tip camera
                              · normalises per-frame, injects error-map noise
                              · state obs: 6 floats (§ Observation)
        ↓
train_sf.py                →  Sample Factory APPO, recurrent (GRU 512)
        ↓
policy checkpoint          →  best_000000940_3850240_reward_1.204.pth
```

### 3. Deployment — the loop that runs on hardware

```
scope tip camera
        ↓  RGB frame
DA3-SMALL + fine-tuned head          ⚠️ output is scale-RELATIVE, not metric
        ↓  depth → resize 54×96 → divide by frame max → clip [0,1]
APPO policy   (depth CNN + state MLP → GRU 512 → Gaussian head)
        ↓  take the MEAN, not a sample
        ↓  a = [bend_x, bend_z, feed_rate] ∈ [-1, 1]³
PD command shaper                     ← its output is also fed back as policy input
        ↓
4 antagonistic tendons  +  insertion feed
        ↓
scope tip
```

Two things in that diagram are easy to get wrong and both have bitten this project:

- **The depth is relative, not metric.** Each frame is divided by its own maximum, so the
  farthest visible point is always exactly 1.0. The policy reads depth *structure* and has no
  access to absolute distance. The fine-tuned model's 1.43 mm figure is scale-aligned against
  ground truth — it is not a distance accuracy available at deploy time.
- **Deployment must take the Gaussian's mean.** The network emits distribution *parameters*.
  Sampling is PPO exploration noise, and measured σ ≈ 0.627 on a ±1 action space dominates the
  command. Taking the mean cuts tip-command jitter by 91%.

---

## The control loop

One decision every **40 ms (25 Hz)**, matching the rate the real depth model can sustain
(measured: 31 fps). Inside each decision the simulator runs **80 physics substeps** at 0.5 ms.

| | |
|---|---|
| **Observation** | `depth (1, 54, 96)` + `state (6,)` |
| **Action** | `Box(-1, 1, (3,))` — X bend setpoint, Z bend setpoint, feed rate |
| **Episode cap** | 2500 steps = 100 s |
| **Max advance** | 1.2 mm/step = 30 mm/s |

### Observation

**Depth** — 54 rows × 96 columns, 16:9, from a `fovy = 67.7°` tip camera, which on 16:9 is
**100.0° horizontal**. Normalised by the per-frame maximum, then multiplicative spatially
structured noise is injected from the error map. Noise scales with depth value, so near walls
get small absolute error and open lumen gets more — matching how monocular depth error grows
with distance.

**State** — six floats, and it matters what they are:

| idx | Value | Kind |
|---|---|---|
| 0–1 | PD filter state, normalised by max pull per axis | software, not a sensor |
| 2–4 | previous **commanded** action | the policy's own echo |
| 5 | `tip_contact`, binary | the only exogenous signal |

Five of the six are software state that a deployment must **reproduce identically, not
measure**. Only `tip_contact` says anything about the world beyond the image.

### What is deliberately *not* observed

This is the design rule that shapes the whole system:

> **Only give the policy signals the simulator can model with genuine fidelity.** Otherwise the
> policy either overfits a fantasy signal or learns to ignore it as noise.

Removed under that rule, each for a specific reason:

- **Contact and actuator forces** (`force_norm`, `net_fx`, `net_fz`, removed 2026-07-10) — clean
  in sim; any physical equivalent is dominated by transmission friction the sim does not model.
- **Cable-pair length differential** (`ten_x_n`, `ten_z_n`, removed 2026-08-04) — the interesting
  case is *inverted* between sim and hardware. In sim a dead zone zeroes the actuator target, so
  the tendon never moves and the policy learns "inside the dead zone, nothing happened." If a
  real dead zone is cable slack, the motor turns and the encoder reads the full command while
  the tip does not move. A reversed signal is worse than a missing one.
- **True colon progress** — privileged sim information, used for reward and diagnostics only.

### Action, and what it drives

`a[0]` and `a[1]` are **absolute bend setpoints, not rates** (×6.795 mm and ×7.361 mm — the two
axes differ because they span 12 vs 13 joints). `a[2]` *is* a rate, accumulating into a
monotonic insertion-depth target.

The setpoints pass through a PD command shaper (τ = 214 ms, 95% settle 640 ms, no overshoot)
whose output is **also observation slots 0–1** — the filter sits inside the observation loop,
not downstream of it. Below that, each of the four tendons runs a length-tracking integral loop
every physics substep, with anti-windup, against a 10 N pull-only force rail. Cables cannot
push.

⚠️ **The PD gains do not rescale arithmetically with control rate.** Moving 100 Hz → 25 Hz by
multiplying the old gains by 4 puts the poles at |z| = 1.337 — a diverging oscillation. This was
verified, not hypothesised. Any future rate change must re-fit against the wall-clock step
response.

Insertion is friction-driven: position-controlled rollers grip the shaft and **can slip**.
Progress is therefore never read from the commanded value — it is measured from the true
physical position of the base link projected onto the colon centreline.

### Reward

```
reward = 4.0 · new_territory            (per metre, high-water-mark only)
       − 0.004/step while the tip is in wall contact
       − 0.05 on a no-progress ending
```

`new_territory` is high-water-mark advance, so going forward, back, and forward over the same
ground earns nothing the second time. **There is no action-smoothness term** — an action-rate
penalty was examined and deliberately rejected, because the per-step progress reward is only
~0.0048 and any weight large enough to matter would train a passive policy.

Episodes end on `shaft_exhausted` or `ejected` (terminated), or `stuck`, `tip_stuck`,
`max_steps` (truncated).

---

## The network

```
depth (1, 54, 96) ──> 3× Conv+ReLU → Flatten 13440 → Linear 512 ─┐
                                                                 ├─ concat 640 ─> GRU(512) ─> Gaussian head (3-D)
state (6,) ─────────> Linear 64 → Linear 128 ────────────────────┘                        └─> value head
```

Both input widths are **derived at construction**, not hardcoded — which is why the 64×64 →
54×96 and 8-D → 6-D changes needed no encoder edit.

**The GRU is load-bearing.** The task is partially observable: a single depth frame does not
disambiguate lumen direction at a haustral fold, so the recurrent state integrates frames across
the approach. Any deployment that re-instantiates the network per frame, or forgets the hidden
state between steps, **is not running the trained policy**.

*Forensic tip:* a checkpoint's `encoder.depth_cnn.net.1.weight` shape tells you which
observation geometry it was trained on — 13440 = current 54×96, 10816 = the old 64×64.

---

## The simulated hardware

**Colon** — each seed is a unique procedural geometry: bends, tube radius and haustral folds all
randomised. Two meshes come from the same parametric surface: a fine **visual** mesh the tip
camera renders against, and a coarser **collision** mesh converted to per-triangle thin prisms
by `mesh_to_thin_prisms.py`, so MuJoCo resolves contacts against the true inner wall rather than
a convex-hull approximation.

**Scope** — a 25-hinge tendon-driven articulating tip (9 mm OD) on a 44-link flexible shaft
(432.5 mm shaft, 495 mm total), fed by an entrance roller/capstan mechanism. This is the
defining difference from the `v6_dr` generation, which moved the scope base kinematically: here
push force must travel around bends through wall contact, so **buckling, slip and jamming are
real failure modes**.

Joint stiffness is `0.055 N·m/rad`, measured at **2.92 N** of cable tension for a full bend.
That figure is a correction: it was `0.5`, needing ~27 N, against a bench measurement of ~3 N.

**Domain randomisation**, drawn once per episode: actuator force gain (0.45–1.0), dead zone
(0–3% of max pull), command lag (0–1 steps). Two honest gaps, both recorded in code — DR never
randomises the command→deflection map (every episode still reaches 98–99% of commanded bend),
and the dead zone is stateless and zero-centred, modelling no backlash or slack take-up on
reversal.

---

## `error_map_64.npy` — the sim-to-real bridge

The single artefact connecting the two pipelines, and the project's main sim-to-real idea:
rather than injecting generic noise, inject *the measured spatial error structure of the actual
deployment model*.

1. Fine-tune DA3 on 1,200 Blender training frames
2. Generate 500 unseen eval frames on different geometry
3. Run inference on those frames
4. Compute per-pixel mean relative error `mean(|pred − gt| / gt)` across all 500
5. Resize to the RL depth resolution

During training, at every observation step:

```python
noise = randn(54, 96) * error_map * depth
depth = clip(depth + noise, 0, 1)
```

⚠️ **Known approximation:** the map was measured on the *old* square 85° camera and is resized
to 54×96, an anisotropic stretch (x×1.5, y×0.84). It is a smooth envelope, so this is a mild
distortion rather than a wrong signal — but it is an approximation, not a verified map at the
current geometry.

---

## Where the sim stops and hardware begins

The simulator states requirements on the rig; it does not describe it. The bring-up status,
measurements, and open mismatches live in [../hardware/README.md](../hardware/README.md), and
the authoritative list of what is still unresolved is
[CURRENT_PLAN.md](CURRENT_PLAN.md) §8.

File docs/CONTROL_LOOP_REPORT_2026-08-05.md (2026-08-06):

# Control-Loop Progress Report — Mujuco_V3 / v8_p1 — 2026-08-05

> **This is a dated snapshot, not a plan.** The single source of truth for where the project is
> and what happens next remains `docs/CURRENT_PLAN.md`. If this document and that one disagree,
> **CURRENT_PLAN.md wins** — this one only records the state of the control loop on the date in
> its title and does not decide anything.

**Snapshot date: 2026-08-05.** Written to be self-contained: it assumes the reader has **no
access to the repository**. Every number below was read directly out of the live code in
`navigation/v8_p1/` on this date, with file and line given so any claim can be traced.

**Scope of this document.** It describes *what the simulator does* — the control loop the
policy was trained inside, the exact tensors it consumes, the exact vector it emits, and the
arithmetic the environment performs between them. Where it says something about hardware, it
is stating **a requirement the sim imposes** ("the rig must supply X in form Y"), never an
assumption about how the physical rig currently behaves. Sections marked *"What the physical
implementation must provide"* are requirements derived from sim; they are not a description of
anything measured on hardware.

---

## 1. Status in five lines

1. The policy is a **trained recurrent PPO agent** (Sample Factory), checkpoint
   `best_000000940_3850240_reward_1.204.pth`, retrained from scratch 2026-08-04 against six
   simultaneous changes to physics, observation geometry, observation content and control rate.
2. Training reported **~97% mean progress** at 4.52M of a 5M step budget. That is a *training*
   statistic computed from **sampled** rollouts (see §7.2). **No evaluation run has been done on
   this checkpoint.**
3. The control loop now runs at **25 Hz** in sim (40 ms per decision), matching the intended
   deployment rate exactly. It used to be 100 Hz.
4. The observation is **one depth image + six scalars**. Everything in the six scalars is either
   the policy's own echo or a binary contact flag — there is no force, tension, current, or
   privileged pose information in it, by explicit design rule.
5. The action is **three numbers in [-1, 1]**: two cable-pair bend setpoints and one insertion
   feed rate.

---

## 2. Loop timing — what "one step" means

| Quantity | Value | Source |
|---|---|---|
| MuJoCo integrator timestep | 0.5 ms | scene XML |
| Physics substeps per decision | **80** | `scope_colon_env.py:138` `DEFAULT_PHYSICS_PER_STEP` |
| Wall-clock per decision | **40 ms → 25 Hz** | 80 × 0.5 ms |
| Fresh depth frames | **every step (25 Hz)** | `scope_colon_env.py:208` `DEPTH_DECIMATION = 1` |
| Episode cap | 2500 steps = **100 s** | `scope_colon_env.py:135` |
| Max commanded advance | 1.2 mm/step = **30 mm/s** | `scope_colon_env.py:136` |

The physics timestep itself was **not** changed when the control rate moved 100 Hz → 25 Hz;
only the number of substeps per decision. Physics cost per simulated second is identical
(2000 mj_steps/s either way) — the change bought decision-rate realism and a 4× shorter credit
assignment horizon, not speed.

`DEPTH_DECIMATION` exists because the loop previously ran at 100 Hz while the depth model could
only produce ~25 Hz; it held the previous frame for 3 of every 4 steps. Now that control is
itself 25 Hz, the mechanism is **inert but still in the code** (`= 1`), and can be raised again
if control and camera rates diverge.

---

## 3. Observation — exactly what the policy is fed

The observation space is a **dict of two entries** (`scope_colon_env.py:628-637`):

```
depth : Box(0, 1, shape=(1, 54, 96), float32)
state : Box(-inf, inf, shape=(6,), float32)
```

### 3.1 `depth` — (1, 54, 96), values in [0, 1]

Produced in `_observation()`, `scope_colon_env.py:1211-1236`:

1. Render the tip camera's depth buffer at **54 rows × 96 columns** (16:9).
   The camera is `fovy = 67.7°` vertical, which on 16:9 is **100.0° horizontal**
   (`build_collision_scene.py`, `TIP_CAM_FOVY`).
2. **Normalise by the per-frame maximum**, not by a fixed metric clip:
   `depth = clip(depth_raw / max(depth_raw), 0, 1)`.
   The farthest visible point in each frame is always exactly 1.0. This makes the obs
   **scale-relative, not metric** — the policy reads relative depth *structure* and has no
   access to absolute distance. (The env docstring mentions a `depth_clip_m`; the code does not
   use it. The code is what the policy was trained on.)
3. Add channel dim → `(1, H, W)`, PyTorch convention, not gym's `(H, W, C)`.
4. Inject **multiplicative, spatially structured noise**:
   `noise = randn(54, 96) * error_map * depth`, then re-clip to [0, 1].
   The error map is a measured envelope of depth-estimation error magnitude. Noise scales with
   depth value, so near walls get small absolute error and open lumen gets larger — matching how
   monocular depth error grows with distance.

⚠️ **Known approximation:** the error map was measured on the *old* square, 85° camera and is
resized to 54×96, which is now an anisotropic stretch (x×1.5, y×0.84). It is a smooth envelope,
so this is a mild distortion rather than a wrong signal, but it is an approximation, not a
verified map at the current geometry.

### 3.2 `state` — 6 floats

Built at `scope_colon_env.py:1252-1256`:

| idx | Name | Definition | What it is |
|---|---|---|---|
| 0 | `cmd_x_n` | `cmd_x_pair / MAX_PULL_X`, `MAX_PULL_X = 6.795 mm` | **Internal PD filter state**, normalised. Not a sensor. |
| 1 | `cmd_y_n` | `cmd_y_pair / MAX_PULL_Z`, `MAX_PULL_Z = 7.361 mm` | Same, other axis. |
| 2 | `last_action[0]` | previous step's **commanded** a[0], clipped to ±1 | Policy's own echo |
| 3 | `last_action[1]` | previous step's commanded a[1] | Policy's own echo |
| 4 | `last_action[2]` | previous step's commanded a[2] | Policy's own echo |
| 5 | `tip_contact` | `float(tip_contact_steps > 0)` — binary 0.0 / 1.0 | Only exogenous signal in the vector |

Two things are worth stating plainly, because they determine what the rig has to supply:

- **Five of the six are software, not sensors.** `cmd_x_n` / `cmd_y_n` are the state of a filter
  the environment runs internally (§5.2), and slots 2–4 are the previous action. None of them is
  read back from the simulated hardware. They must be **reproduced in software identically** on
  any deployment, not measured.
- **`tip_contact` is the only thing the policy learns about the world other than the depth
  image.** In sim it resolves as *any* contact between the last tip disk (the one carrying the
  camera, 9.0 × 1.68 mm) and the colon wall body — which includes the cylinder's side face,
  both flat end faces, and the joint ball. It is deliberately blind to tip-vs-shaft
  **self**-contact, so that tip curl-back does not read as a wall jam.

`tip_contact` is **not obs-only**: the same flag drives a per-step reward penalty and a
truncation condition (§6).

### 3.3 What was deliberately removed from the observation, and why

This is a design rule the project applies consistently, and it explains why the obs is as thin
as it is:

> **Only give the policy signals the simulator can model with genuine fidelity.** Otherwise the
> policy either overfits a fantasy signal or learns to ignore it as noise.

Removed under that rule:

- **`force_norm`, `net_fx`, `net_fz`** (removed 2026-07-10). Summed raw contact force and
  actuator-force readouts. In sim these are clean; any physical equivalent would be dominated by
  transmission friction the sim does not model.
- **`ten_x_n`, `ten_z_n`** — antagonistic cable-pair length differential, i.e. an encoder-like
  reading (removed 2026-08-04, taking the state vector 8-D → 6-D). Three reasons, documented at
  `scope_colon_env.py:248-289`:
  1. **Redundant in the normal case.** `MAX_PULL_X = 6.795 mm` against a pair range of
     `13.380 mm` — ratio 1.97, so the two normalisations land on the same scale and
     `ten_x_n ≈ cmd_x_n` whenever nothing is resisting.
  2. **The dead-zone case is inverted.** In sim a dead zone zeroes the actuator target, so the
     tendon never moves and the policy learns *"inside the dead zone, the encoder shows nothing
     happened."* If a dead zone on real hardware is cable slack, the motor turns and the encoder
     reads the full command while the tip does not move — the opposite reading. A reversed
     signal, not merely a weaker one.
  3. **Sim over-reports load.** Sim's position actuator visibly droops under resistance; a stiff
     closed-loop servo would hold position and draw current instead.

  Note this removed only the **observation**. Tendon length is still read every physics substep
  to drive the actuator control loop (§5.4).
- **True colon progress** is never observed. It is privileged sim information used only for
  reward and diagnostics.

---

## 4. The network — how the observation becomes an action

`sf_encoder.py` plus Sample Factory's actor-critic head.

```
depth (1, 54, 96) ──> Conv(1→32, k3, s2)  → ReLU     54→26  |  96→47
                      Conv(32→64, k3, s2) → ReLU     26→12  |  47→23
                      Conv(64→64, k3, s1) → ReLU     12→10  |  23→21
                      Flatten  10×21×64 = 13440
                      Linear(13440 → 512) → ReLU  ──────────────┐
                                                                ├─ concat → 640
state (6,) ─────────> Linear(6 → 64) → ReLU                     │
                      Linear(64 → 128) → ReLU ──────────────────┘
                                     │
                                     ▼
                          GRU, hidden size 512          (rnn_type=gru, recurrence=64)
                                     │
                        ┌────────────┴────────────┐
                        ▼                         ▼
              policy head → (mean, log_std)   value head → V(s)
                 3-D Gaussian
```

Both input widths are **derived at construction**, not hardcoded: the CNN sizes its flatten
layer from a `torch.zeros` probe, and the state MLP reads `obs_space["state"].shape[0]`. This is
why the 64×64 → 54×96 and 8-D → 6-D changes needed no encoder edit.

Useful forensic fact: a checkpoint's `encoder.depth_cnn.net.1.weight` shape tells you which obs
geometry it was trained on — **13440** = current 54×96, 10816 = the old 64×64.

**The GRU is load-bearing for the loop.** The hidden state must be carried from step to step and
zeroed **only** at episode start. Any deployment that re-instantiates the network per frame, or
forgets the hidden state, is not running the trained policy.

---

## 5. Action — what the agent emits, and the whole chain it drives

### 5.1 The action vector

`action_space = Box(-1, 1, shape=(3,), float32)` (`scope_colon_env.py:623`)

| idx | Meaning | Units after mapping |
|---|---|---|
| `a[0]` | X-axis cable-pair bend **setpoint** | ×6.795 mm = commanded pull, metres |
| `a[1]` | Z-axis cable-pair bend **setpoint** (called "y" internally) | ×7.361 mm = commanded pull, metres |
| `a[2]` | Insertion **feed rate**, signed | ×1.2 mm per step = ±30 mm/s |

`a[0]` and `a[1]` are **absolute position setpoints, not rates.** A rate-based action was
proposed and explicitly rejected: "command a pull amount" is the intended native interface.

`a[2]` is a **rate** — it accumulates into a monotonic insertion-depth target, see §5.3.

The action is clipped to ±1 on entry (`step()`, `scope_colon_env.py:895`).

### 5.2 Step 1 — the PD command shaper (this is a policy input, so it matters most)

`scope_colon_env.py:902-915`, run once per 25 Hz decision:

```python
target_x = a[0] * MAX_PULL_X          # 6.795 mm
target_y = a[1] * MAX_PULL_Z          # 7.361 mm

vel_x = cmd_x_pair - prev_cmd_x       # note: velocity of the FILTER, not of the tip
vel_y = cmd_y_pair - prev_cmd_y
prev_cmd_x, prev_cmd_y = cmd_x_pair, cmd_y_pair

cmd_x_pair = clip(cmd_x_pair + PD_KP*(target_x - cmd_x_pair) - PD_KD*vel_x, ±MAX_PULL_X)
cmd_y_pair = clip(cmd_y_pair + PD_KP*(target_y - cmd_y_pair) - PD_KD*vel_y, ±MAX_PULL_Z)

PD_KP = 0.1803        PD_KD = 0.0475        # scope_colon_env.py:153-154
```

Measured response of this filter at 25 Hz: **τ = 214 ms**, 95% settle **640 ms**, **0.000%
overshoot**, reversal slew 0.75×.

Three points that a reimplementation gets wrong easily:

- **`cmd_x_pair` after this update is what the policy observes** as `cmd_x_n`. The filter is
  inside the observation loop, not downstream of it.
- **The gains do not rescale arithmetically with rate.** Moving 100 Hz → 25 Hz by multiplying
  the old gains (0.06, 0.30) by 4 gives poles at |z| = 1.337 — **unstable, a diverging
  oscillation**. This was verified, not hypothesised. The current values were fitted against the
  wall-clock step response instead. Any future rate change must re-fit, not re-scale.
- **Order matters:** velocity is computed from the *previous* two filter states before the
  update, and the clip is applied inside the assignment.

### 5.3 Step 2 — insertion accumulator

`scope_colon_env.py:944-956`:

```python
ds_command = a[2] * 1.2 mm
target_insertion_depth = max(0.0, target_insertion_depth + ds_command)   # metres, monotonic floor at 0
roller_ctrl = -target_insertion_depth / 0.008          # radians; 8 mm roller radius
```

The rollers are position-controlled and grip the shaft by **friction**. They can slip. Progress
is therefore *never* read from this commanded value — it is measured from the true physical
position of the base link projected onto the colon centreline (`actual_base_s`,
`scope_colon_env.py:1004-1006`). The sim models advance **lagging** the command via slip, and
never **exceeding** it.

### 5.4 Step 3 — cable mapping and the inner control loop

Antagonistic mapping (`scope_colon_env.py:930-933`), four tendons in order px, pz, nx, nz:

```
ctrl[px] = +cmd_x        ctrl[nx] = -cmd_x
ctrl[pz] = +cmd_y        ctrl[nz] = -cmd_y
```

Then **80 physics substeps**, and inside *every* substep (`scope_colon_env.py:969-977`) each of
the four tendons runs a length-tracking integral loop:

```python
target_len     = REST_LENGTH - ctrl[pull_actuator]
length_error   = ten_length[tendon] - target_len
combined_force = actuator_force[P] + actuator_force[I]
saturated      = combined_force <= (-10.0 N + 0.25 N)     # ANTIWINDUP_FORCE_MARGIN
ctrl[integral_actuator] = 0.0 if saturated else length_error   # freeze accumulator = anti-windup
mj_step()
```

Actuator constants (`generate_videoscope_one_section.py`): `ACTUATOR_KP = 6000`,
`ACTUATOR_KI = 36000`, `forcerange = [-10, 0] N` — **pull only, cables cannot push**. Joint
`stiffness = 0.055 N·m/rad`.

That stiffness figure is the result of the most recent physics correction: it was `0.5`, which
required ~27 N of cable tension for a full bend. It is now `0.055`, measured at **2.92 N** for
100% of nominal bend on both axes, with zero drift and no folding over 40 simulated seconds.
The force rail came down 80 N → 10 N to match. Under the PD shaper — i.e. real training
conditions rather than an artificial step — peak tendon tension is **~7.8 N against the 10 N
rail**, so anti-windup never engages in normal operation.

### 5.5 Domain randomisation — training only, and what it does *not* cover

Drawn once per episode in `reset()` (`scope_colon_env.py:842-866`):

| Parameter | Range | Applied to |
|---|---|---|
| gain X / Y | 0.45 – 1.0 | actuator **force** output (both the P and I actuator) |
| dead zone X / Y | 0 – 3% of max pull | zeroes `ctrl` when the command is below threshold |
| command lag | 0 – 1 steps (0 – 40 ms) | ring buffer on the effective command |

Two honest limitations, both recorded in the code:

- **DR never randomises the command→deflection map.** The gain scales *force*, and with the
  integral actuator every episode still reaches 98–99% of commanded bend regardless. "Command
  0.5, get 0.5" has held in every episode ever trained.
- **The dead zone is stateless and zero-centred.** It models no slack take-up on direction
  reversal, and no hysteresis or backlash of any kind.

---

## 6. Reward and episode boundaries — what the loop was optimised for

Not part of a deployment loop, but it defines the behaviour:

```
reward = W_PROGRESS · new_territory        (W_PROGRESS = 4.0, per metre)
       − W_TIP_PENALTY  while tip in wall contact   (0.004/step = 0.1 /s)
       − W_STUCK_PENALTY on a no-progress ending    (0.05, terminal)
```

`new_territory` is **high-water-mark** advance in metres — going forward, back, and forward over
the same ground earns nothing the second time. Force-based reward discounts and lumen bonuses
exist in the code but are all zeroed.

| Ending | Type | Condition |
|---|---|---|
| `shaft_exhausted` | terminated | base of the shaft physically reached the feed rollers |
| `ejected` | terminated | scope backed out past its start by 50 mm |
| `stuck` | truncated | < 2 mm of new territory over a 75-step (3.0 s) window |
| `tip_stuck` | truncated | tip in wall contact for 38 consecutive steps (1.5 s) |
| `max_steps` | truncated | 2500 steps (100 s) |

**There is no action-smoothness term in the reward at all.** This was examined and an
action-rate penalty was deliberately **rejected**, on two grounds: the per-step progress reward
is only ~0.0048, so any weight large enough to matter would dominate it and train a passive
policy; and the deterministic action is already smooth (§7.2), so the failure such a penalty
prevents is not occurring.

---

## 7. The loop as it must actually run

### 7.1 Deployment loop, in order

```
                 ┌─────────────────────────────────────────────┐
                 │  once per 40 ms (25 Hz)                     │
                 └─────────────────────────────────────────────┘

  1.  DEPTH        camera frame → depth estimate → resize to 54×96
                   → divide by the frame's own maximum → clip [0,1] → shape (1,54,96)

  2.  STATE        assemble 6 floats:
                     [ cmd_x_pair/MAX_PULL_X,        ← filter state from the PREVIOUS iteration
                       cmd_y_pair/MAX_PULL_Z,
                       last_action[0..2],            ← the previous COMMANDED action
                       tip_contact (0.0 or 1.0) ]

  3.  INFERENCE    features = concat(CNN(depth) 512, MLP(state) 128)   → 640
                   h_t, out = GRU(features, h_{t-1})                    ← hidden state PERSISTS
                   a = policy_head(out).means                           ← the MEAN, not a sample
                   a = clip(a, -1, 1)

  4.  SHAPE        target = a[0:2] · [MAX_PULL_X, MAX_PULL_Z]
                   run the PD update of §5.2  → cmd_x_pair, cmd_y_pair
                   (these become the next iteration's obs slots 0 and 1)

  5.  DRIVE        cable X: pull +cmd_x_pair, release the opposing cable by the same amount
                   cable Z: pull +cmd_y_pair, release the opposing cable by the same amount
                   insertion: target_depth = max(0, target_depth + a[2]·1.2 mm)

  6.  ECHO         last_action = a       ← store the COMMANDED action, not anything measured
```

Step 6 is worth flagging: the sim stores the **commanded** action
(`scope_colon_env.py:1121`), so feeding back the command rather than a measured deflection is
faithful to what the policy was trained on.

### 7.2 Deterministic vs sampled — read this before judging any playback

The network emits Gaussian **parameters**, not an action. Sample Factory's `forward()` defaults
to `sample_actions=True`, so its `actions` output is a fresh draw `μ + σ·ε` — PPO's exploration
noise, redrawn every step. **Measured σ ≈ 0.627 on a ±1 action space**, so a sampled command is
dominated by noise.

| Measurement | Sampled | Deterministic (mean) |
|---|---|---|
| tip-command jitter, RMS mm/step | 0.985 | **0.093** (−91%) |
| mean \|a_xy\| (steering magnitude) | 0.468 | **0.034** |
| same obs ×5, action spread | [0.589, 0.376, 0.711] | **[0, 7e-9, 0]** |

Consequences:

- **Deployment must take the mean.** The viewer was changed to do this by default on 2026-08-04;
  before that it was showing training-mode noise and the policy looked violently unstable.
- The **~97% training figure was earned with σ ≈ 0.63 of command corruption injected**, because
  Sample Factory's training statistics come from sampled rollouts. The deterministic policy
  should be at least as good — the noise was not concealing a bad policy.
- **The evaluation script still samples.** Every archived eval number in this project, across all
  versions, was produced in sampling mode. An eval on this checkpoint has not been run at all.

**One unresolved question about the action itself.** Deterministic mean `|a_xy|` is only
**0.034** — about 3.4% of full bend. It is not yet established whether the policy is steering
efficiently with small precise corrections, or barely steering at all and letting shaft
compliance and colon geometry do the work. The second would transfer badly. The check is cheap
and specified but **not yet run**: log deterministic `|a_xy|` across full traverses and test
whether it *rises at bends*.

---

## 8. What a physical implementation must provide

Requirements the sim imposes. Nothing here describes hardware behaviour — it states what the
loop above needs in order to run at all.

| The policy consumes | Form it must arrive in | Nature |
|---|---|---|
| `depth` (1, 54, 96) | float32 in [0,1], **normalised by each frame's own maximum**, from a view equivalent to **100.0° horizontal × 67.7° vertical rectilinear**, 16:9 | perception pipeline |
| `cmd_x_n`, `cmd_y_n` | the PD filter of §5.2, reimplemented **exactly** — same gains, same update order, same clip, ticked once per 40 ms | **software, not a sensor** |
| `last_action[0..2]` | the previous **commanded** action | software |
| `tip_contact` | binary 0/1 | contact sensing |
| **The policy emits** | | |
| `a[0]`, `a[1]` | **absolute pull setpoints** in metres after scaling by MAX_PULL — a position command, not a rate | position/encoder control |
| `a[2]` | signed feed **rate**, full scale = 1.2 mm per 40 ms = 30 mm/s | insertion drive |

**Hard requirements before the loop can be trusted:**

1. **`MAX_PULL_X` and `MAX_PULL_Z` must be measured on the real scope.** The sim's 6.795 mm and
   7.361 mm are derived from sim geometry. They normalise `cmd_x_n` / `cmd_y_n` — *two of the six
   policy inputs* — and they scale the action into physical units. This is a correctness
   requirement, not a refinement. **Keep the two axes separate**: they differ because the X axis
   spans 12 joints and Z spans 13; do not collapse them to one number.
2. **The depth view must be rectilinear at 100° horizontal.** The sim camera and the depth
   model's training camera are the same camera by construction (both renderers are rectilinear
   16:9, and `fovy = 67.7°` on 16:9 gives exactly 100.03° horizontal). A wider real lens is
   necessarily barrel-distorted, and the correction is a perception-side remap to a
   100°-horizontal rectilinear virtual camera — a precomputed lookup table, one remap per frame.
   It changes only what the camera hands the depth model; it does not touch what sim renders.
3. **The GRU hidden state must persist across the loop** and reset only at the start of a run.
4. **Take the distribution mean, not a sample** (§7.2).

### 8.1 ⚠️ Camera frame — MUST BE MEASURED ON THE REAL SCOPE (added 2026-08-06)

**The scope camera already exists in hardware, so this is a measurement, not a design choice.**
Nothing below is a claim about how the physical camera is mounted — it states what sim does and
what must be tested against it.

**What sim does — certain, read straight off the model.** The tip camera is declared as a child
of the `disk_25` body (`build_collision_scene.py:862`):

```xml
<camera name="tip_cam" pos="0 0.0025 0" xyaxes="-1 0 0 0 0 -1" fovy="67.7"/>
```

No `mode` attribute, so MuJoCo defaults to `mode="fixed"` — rigidly welded to the tip body
frame, not tracking anything. **Nothing touches it at runtime.** The only two references in the
whole environment are one ID lookup at construction (`scope_colon_env.py:616`) and passing that
ID to `update_scene` (`:1214`). There is no write to `cam_pos`, `cam_quat` or `cam_xmat`
anywhere. **The sim camera is never rotated, and there is no roll stabilisation, horizon
levelling, or gravity-up reference anywhere in the loop.**

**Why that is the useful property.** The tendon holes live in the *same body frame* as the
camera (`hole_px_25` at body +X, `hole_nx_25` at −X, `hole_pz_25` at +Z, `hole_nz_25` at −Z).
Image and cables are therefore locked to one another, and **the relation between "where the
lumen is in the image" and "which cable steers toward it" is a constant of the system.** The
scope twists continuously as it rounds bends; the policy neither sees nor cares, because input
and output rotate together. This is why the 6-D state carries no orientation term and why
nothing breaks without one. Only a single **fixed roll offset** between the real camera and the
real cable axes can matter.

**The convention sim was trained under** (derived from `xyaxes` and MuJoCo's camera convention —
+X image right, +Y image up, looks down −Z; frame verified right-handed, so no mirroring):

| | Body frame | Cable pair | Joints / range / max pull |
|---|---|---|---|
| image **right** | body **−X** | `px`/`nx` | 12 joints, 120°, 6.795 mm |
| image **up** | body **−Z** | `pz`/`nz` | 13 joints, 130°, 7.361 mm |
| optical axis | body **+Y** (forward) | — | — |

Hence `a[0] > 0` → bends toward +X → **steers toward image LEFT**; `a[1] > 0` → bends toward +Z
→ **steers toward image DOWN**. Note also that the **wide** image axis (100° over 96 columns) is
the X pair and the **narrow** axis (67.7° over 54 rows) is the Z pair.

**THE TEST TO RUN. Do not measure the camera's mechanical roll and the cable positions
separately** — that yields two numbers with two error bars, when the quantity that matters is
the *relation* between them. Measure it directly:

> **Scope in free space. Pull each of the four cables in turn to a clearly visible bend, and
> record which way the image content translates.** Four pulls gives the complete image↔cable
> map — offset angle *and* all signs — with no calibration target, in exactly the frame the
> policy cares about.

**Acting on the result:**

- **Offset is a multiple of 90°** → fix in software with a **signed swap of `a[0]`/`a[1]`**.
  Relabelling the cables and rotating the command are the same operation here. No image
  rotation, no resampling, no aspect problem. **180° is exactly free.** 90°/270° costs the
  12-vs-13 joint asymmetry — `a[0]` would drive a 130° axis where sim trained it on 120°, about
  8% in pull and 10° in range.
- **Offset is NOT a multiple of 90°** → **it cannot be corrected in the action**, and the reason
  is the field of view rather than the network. The obs is **1.04°/column against 1.25°/row**, so
  a feature at 45° in the world does not land at 45° in the image: a rolled real frame is not a
  rotation of any frame sim can produce, and the distortion is already baked into the pixels the
  CNN reads. Secondary reasons pointing the same way: the CNN is not rotation-equivariant
  (convolutions are translation-equivariant, and the flatten→linear head discards even that);
  the bend map is itself anisotropic so a rotated command is not a rotated bend, with an
  elliptical reachable envelope that a rotated full-scale command can exceed; and the GRU's
  recurrent state goes out of distribution too. Fix the mount if possible, or rotate the frame
  **before** the downscale to 54×96 and absorb the crop there — this folds into the fisheye
  rectification remap §8 already requires for the 122°-vs-100° horizontal gap, so it is one LUT
  and no extra per-frame cost.

**⚠️ Trap, whichever route is taken.** Five of the six state slots are the action echo
(`last_action[0..2]`, plus the two PD filter slots derived from it). **They must be expressed in
the same frame as the image.** Rotating the outgoing command while feeding back the unrotated
one — or the reverse — hands the policy an image/echo pair that contradicts itself, a condition
it has never seen in training.

**Confidence.** That the sim camera never rotates is *structural and certain*. The specific sign
convention in the table above is **derived** from the XML and MuJoCo's camera convention, **not
measured** — the headless check (drive `a[0] = +1`, observe which way depth structure shifts) is
specified but **has not been run**. Run it before committing hardware wiring to the signs.

**Design rules already settled, which constrain any low-level implementation:**

- **Position/encoder control, not tension control.** This is decided.
- **Force sensing may drive the low-level loop and safety limits. It must never be a policy
  input.** Same rule that removed `force_norm` and the tension observations.
- If a tension-triggered safety governor is ever added underneath (e.g. slow the motor when line
  tension is high), the policy should be **robust to** it, not trained on it. That would,
  however, make an encoder observation deviate from command in a way sim already models, and
  would be a reason to revisit the removed `ten_*` inputs.

---

## 9. Known gaps in the sim's own control loop

Stated plainly, because they bound what the loop can currently claim.

1. **⚠️ The feed mechanism does not transport at slow insertion rates.** With the feed rate
   scaled to 10% (3 mm/s) and a fixed open-loop `[0, 0, 1]` action — **no policy involved** —
   the scope advances **9.45 mm and then stops permanently**, while the commanded insertion
   accumulator climbs to 84 mm. Roller actuator force stays at ~0.02–0.09 N and does not grow
   with the 74 mm position error. Same seed and action at full rate: 96 mm in 109 steps. So the
   friction-grip feeder transports at 30 mm/s and fails to transport at 3 mm/s.
   **Consequence: the sim cannot presently represent a slow, hand-paced insertion**, and the
   policy has only ever experienced 1.2 mm of visual progress per decision. Whether the GRU
   depends on that rate is **unknown and untestable until this is diagnosed.** Suspects: roller
   contact friction, solver contact parameters, actuator velocity gain. Note that fixing it may
   change behaviour at 30 mm/s and invalidate the current checkpoint.
2. **No transmission state.** The dead zone is stateless and zero-centred; there is no slack
   take-up on direction reversal, no hysteresis, no backlash, no pretension state. The sim has a
   pull-only force constraint, but no *slack* variable.
3. **The command→deflection map is never randomised.** See §5.5. The policy has never seen a
   tip that does not go where it is told.
4. **The depth error map predates the current camera geometry.** See §3.1.
5. **No evaluation on the current checkpoint**, and the one steering-quality question that would
   change how a failed trial is read (§7.2) is not yet answered.
6. **The camera roll offset is unmeasured (§8.1).** Sim's image↔cable relation is fixed and known
   by derivation, but the real scope's has never been tested against it. If it is off by a
   non-multiple of 90° it cannot be corrected in the action, only in the frame. The four-cable
   pull test settles it and has not been run.

---

## 10. Change log for the control loop, 2026-08-02 → 2026-08-04

Six changes shipped together in one retrain; all were verified by inspecting the trained
checkpoint's weight shapes, not assumed.

| | Change | Effect on the loop |
|---|---|---|
| **A** | Tendon force scale: joint stiffness 0.5 → 0.055, force rail 80 N → 10 N | Full bend now costs **2.92 N** instead of 26.57 N |
| **B** | Depth decimation mechanism added (25 Hz depth under 100 Hz control) | Superseded by F; now inert at `= 1` |
| **C** | Camera geometry: square 85° → **16:9, fovy 67.7°**; obs 64×64 → **54×96** | Sim camera and the depth model's training camera became the same camera |
| **D** | Shaft damping 0.3 → 0.05 (plus a hardcoded joint-damping bug fixed) | Traverse:relaxation time ratio 1.7 → 10.2 |
| **E** | Dropped `ten_x_n`/`ten_z_n`; state **8-D → 6-D** | Removed the one observation that was *inverted* against a real encoder |
| **F** | Control rate **100 Hz → 25 Hz** (80 substeps/step) | Matches the deployment rate; 11 step-denominated constants rescaled, PD gains **re-fitted, not scaled** |

Everything step-denominated was rescaled to hold its wall-clock meaning fixed — advance
0.3→1.2 mm/step (30 mm/s), episode cap 10000→2500 steps (100 s), stuck window 300→75 steps
(3.0 s), tip-stuck 150→38 steps (1.5 s), tip penalty 0.001→0.004/step (0.1/s). The
progress weight is per-metre and did **not** change. The ratio
`W_PROGRESS·ADVANCE / W_TIP_PENALTY` was verified unchanged at 1.200.

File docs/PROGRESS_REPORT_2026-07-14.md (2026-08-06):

# Progress Report — 14 Jul 2026

**Headline:** V8 Phase 1 passed. Mean progress **63.2% → 93.5%**; `tip_stuck` failures **73.3% → 12.3%**
without `stuck` rising to replace them (2.4%). The remaining failure was an *environment bug*
(a truncation window that made sharp bends unsolvable at any skill level), not a policy limit.

Awaiting the eval run to confirm — it also settles whether there is a real ~95% progress ceiling.

---

## 1. Actuation — two nested loops

**Outer (per RL step): PD command shaper.** Policy outputs a bend setpoint in [-1, 1] → scaled to the
measured physical pull limits (6.80 mm X / 7.36 mm Z, read off the joint stops, not guessed).
PD (Kp 0.06, Kd 0.30, over-damped) ramps the *command*. Cables driven antagonistically.

**Inner (per physics substep): P+I tendon force law.**
- Original actuator is **pure proportional** (Kp 6000) — a virtual spring, limited to −80…0 N
  (a cable pulls, never pushes).
- Problem: against the tip's joint springs, P-only settles **short of target** (zero error = zero
  force). Capped bend at **35–45% of nominal**.
- Fix: a **separate integral actuator per tendon** (Ki 36000, MuJoCo `dyntype="integrator"`), fed the
  live length error each substep, with **anti-windup** (freezes within 2 N of the 80 N cable limit).
  Forces sum on the shared tendon; the original actuator's stroke limit stays physically honest.
- Result: **~98–99% of commanded bend in 1–2 s**, stable, S-shaped folding drift gone.

**Third channel:** entrance feed rollers — friction grip that can *slip*, so progress is always
measured from the tip's true position, never the commanded roller angle.

## 2. What the obs vector needs in real life

8-D state + 64×64 depth image.

| Field | Hardware requirement |
|---|---|
| `cmd_x`, `cmd_y` | Nothing — controller's own setpoint |
| `ten_x`, `ten_z` | Motor/encoder position per cable. Wire is near-inextensible → proximal reel-in **is** the tendon length, not an approximation |
| `last_action[0..2]` | Nothing — policy's own last output |
| `tip_contact` | Binary "tip touching wall". **The one sensor not yet built** |
| `depth` | Monocular depth estimator on the tip camera — the fine-tuned DA3 model (**1.60 mm** MAE vs 8.30 mm zero-shot) |

**Design rule:** only signals sim can model with *genuine fidelity* — kinematic / encoder / contact.
Force signals were **removed** in Phase 1: in sim they're a clean readout, on hardware they'd be motor
current dominated by unmodelled cable-sheath friction. Either the policy trusts a fantasy signal, or
it learns to ignore it. (They still drive reward and diagnostics — just not what the policy sees.)
True colon progress is privileged sim info and is likewise excluded.

## 3. How sim is matched to reality

1. **Obs parity** — nothing in the policy's input is unavailable at deployment.
2. **Measured depth noise** — the *actual per-pixel error map* of the deployed depth model is injected,
   scaling with distance. Not white noise.
3. **Domain randomisation** each episode — cable efficiency 0.45–1.0, dead zone 0–3%, command lag 0–2
   steps. Applied to actuator *force*, not the target (endpoint stays reachable; effort varies) — and
   applied to the integral actuators too, so the policy can't bypass DR by leaning on them.
4. **Calibrated limits** — pull ranges measured against joint stops; 80 N cable limit; cannot push.
5. **Low-level loops deliberately independent** — sim runs P+I+anti-windup, the rig will run its own
   encoder PID. The policy never sees the actuator mechanism, so only *response characteristics* need
   to match, not implementations.

**Known gaps:** zero gravity; colon not anatomically oriented; tip contact sensor unbuilt; cable stretch
assumed negligible.

## 4. Phase 2 — in brief

**Gravity + an anatomical (left-lateral-decubitus) colon.** They must land *together*: today each seed's
bends use a random 3D axis, so there is no canonical "up" — gravity alone would be meaningless, and
reorienting the colon alone changes nothing. Goal: a policy that actively steers **against** gravity.

Two hard blockers:
- The colon currently runs straight *up* the gravity axis — naive gravity would drag the scope back out
  on almost every episode.
- Most of the shaft hangs outside the colon at reset with no floor in the scene → needs per-body gravity
  compensation (unproven here; has an explicit verification gate before anything is built on it).

Obs/action shapes are **unchanged** (no network surgery), but the physics change enough to need a
**from-scratch retrain**. The real cost is expected to be re-tuning the shaft/roller constants — every
one of them was tuned at zero-g with no shaft weight on the rollers.

**Open question for the meeting:** "if it looks good Phase 2 can start" sets a *gate* — but who owns
writing the Phase 2 plan?

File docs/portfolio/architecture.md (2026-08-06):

> ⚠️ **Harvested 2026-08-06 from the v6_dr portfolio snapshot (`colonoscope-rl`, last touched
> 2026-06-30). NOT yet refreshed for v8_p1.** It describes the kinematic-base v6 line — no
> physical flexible shaft, no roller/capstan feeder, and the pre-v7 observation design. Anything
> here is superseded by [`../CURRENT_PLAN.md`](../CURRENT_PLAN.md) and
> [`../ITERATION_HISTORY.md`](../ITERATION_HISTORY.md), which win in any disagreement.

# System Architecture

## Overview

The system couples three independently developed pipelines — perception, simulation, and control — into a single end-to-end RL training loop, then deploys the trained policy using only onboard sensor data.

### Perception pipeline (run once to produce error_map_64.npy)

```
blender_depth_dataset.py       →  1,500 Blender RGB + depth pairs  →  dataset_finetune/
        ↓
filter_void_frames.py          →  cleaned training dataset (removes black-pixel frames)
        ↓
finetune_da3.py                →  da3small_finetune_head.pth

blender_depth_dataset_eval.py  →  500 unseen RGB + depth pairs     →  dataset_eval_500/
        ↓
run_da3_inference.py \
  --dataset_dir dataset_eval_500 \
  --output_dir predictions_eval_500 \
  --checkpoint checkpoints/da3small_finetune_head.pth
        ↓
compute_error_map.py           →  error_map_64.npy  (64×64 spatial noise map)
```

### RL training pipeline (consumes error_map_64.npy)

```
colon_generator.py         →  procedural 700 mm colon meshes (visual + collision STL)
        ↓
build_collision_scene.py   →  assembled MuJoCo XML scene
        ↓
scope_colon_env.py         →  Gymnasium environment
  · renders 64×64 depth from tip_cam
  · injects error_map_64.npy noise into depth obs each step
  · state obs: [cmd, force_norm, net_fx, net_fz, last_action, tip_contact]
        ↓
train_sf.py  (APPO, 80 parallel envs, GRU 512D)
        ↓
policy checkpoint  →  best_000000728_2981888_reward_1.238.pth
```

### Deployment

```
Real colonoscope camera
        ↓  RGB frame
DA3-SMALL  (base weights + da3small_finetune_head.pth)
        ↓  metric depth image
APPO policy  (GRU 512D + NatureCNN encoder)
        ↓  action: [steer_x, steer_y, advance]
PD tendon controller  (Kp=0.06, Kd=0.30)
        ↓  motor commands
Scope tip
```

---

## Component detail

### Procedural colon environment (`navigation/colon_generator.py`)

Each training seed produces a unique 700 mm colon geometry with 2–4 bends (80–150°), a random tube radius (18–30 mm), and 8–24 haustral folds. Two meshes are generated from the same parametric surface:

- **Visual mesh** (500 axial × 36 radial rings) — what the tip camera renders against; includes a 200 mm straight distal tail so the camera does not see an artificial void near completion.
- **Collision mesh** (125 axial × 20 radial rings) — used for contact physics. Coarser to hit the ~1,500 physics steps/sec target. Converted to per-triangle thin prisms by `mesh_to_thin_prisms.py`, which lets MuJoCo resolve contacts against the inner wall surface rather than approximating it with convex hulls.

### Videoscope model (`simulation/videoscope/`, bundled into `navigation/`)

25-hinge tendon-driven articulating section (9 mm OD, 2.5 mm disk spacing). Four antagonistic tendon pairs controlled via affine-gain actuators. A 1-DOF slide joint with dynamic floor constraint prevents the scope backing out of the colon entrance, which caused a "drag-and-flip" orientation exploit during early training.

Run the interactive manual viewer to explore the scope mechanics:
```bash
cd simulation/videoscope
python manual_tendon_viewer.py
```

### Depth perception pipeline (`perception/`)

**Dataset generation** (`blender_depth_dataset.py`) — self-contained Blender Python script (runs as `blender --background --python blender_depth_dataset.py`). Procedurally generates colon geometry inside Blender, applies a physically-based Cycles material (subsurface scattering, specular IOR, mucosal texture), places a camera on a random centreline path, and renders RGB + metric depth pairs using an emission-shader depth pass. Requires Blender 4.0+ for the Principled BSDF node API.

**Fine-tuning** (`finetune_da3.py`) — head-only fine-tune of DA3-SMALL (DualDPT head, 3.87M / 34.3M params). Backbone frozen. Mixed scale-invariant log + L1 loss. Reduces zero-shot val MAE from 8.30 mm to 1.60 mm, validated on the held-out final geometry of the training set (frames 1200–1499).

**Error map** (`compute_error_map.py`) — computes a 64×64 spatial map of DA3's mean relative per-pixel error on held-out eval frames. This map (`error_map_64.npy`) is the bridge between the perception and RL pipelines: it is injected multiplicatively into MuJoCo depth observations during training so the RL policy learns to be robust to the same spatial noise pattern it will encounter when DA3 runs on real hardware.

### RL controller (`navigation/`)

**Environment** (`scope_colon_env.py`) — Gymnasium environment wrapping the MuJoCo scene. Observation space: `Dict{depth: (1, 64, 64), state: (10,)}`. Action space: `Box(-1, 1, (3,))` — steer X, steer Y, advance rate. Depth is rendered from `tip_cam`, normalised by the max value in the frame (not a fixed clip), and noise-injected via `error_map_64.npy`.

**Encoder** (`sf_encoder.py`) — custom NatureCNN processing the 64×64 depth image into a 512D feature vector. This is registered as a SampleFactory custom encoder and replaces SF's default CNN. The depth features are concatenated with the 10D state obs and fed into the GRU.

**Policy** (`train_sf.py`) — SampleFactory APPO with a 512D single-layer GRU. The GRU is necessary because the task is partially observable: a single depth frame does not disambiguate lumen direction at a haustral ring. The GRU integrates frames across the approach to build a directional estimate.

---

## How `error_map_64.npy` connects perception and navigation

This file is the key sim-to-real bridge and appears in both `navigation/` (bundled for the RL env) and is generated by `perception/compute_error_map.py`.

The pipeline that creates it:
1. Fine-tune DA3 on 1,200 Blender training frames (`finetune_da3.py`)
2. Generate 500 unseen eval frames on different geometry (`blender_depth_dataset_eval.py` → `dataset_eval_500/`)
3. Run inference on those 500 frames (`run_da3_inference.py --dataset_dir dataset_eval_500 --output_dir predictions_eval_500`)
4. Compute per-pixel mean relative error: `mean(|pred − gt| / gt)` across all 500 frames (`compute_error_map.py`)
5. Resize to 64×64 to match the RL depth resolution → `error_map_64.npy`

During RL training, at every observation step:
```python
noise = N(0, error_map_64) × depth_obs
depth_obs += noise
```

Noise is multiplicative so close walls get small absolute noise and open lumen gets larger absolute noise — matching how monocular depth error scales with distance.

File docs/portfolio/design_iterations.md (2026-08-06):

> ⚠️ **Harvested 2026-08-06 from the v6_dr portfolio snapshot (`colonoscope-rl`, last touched
> 2026-06-30). NOT yet refreshed for v8_p1.** It describes the kinematic-base v6 line — no
> physical flexible shaft, no roller/capstan feeder, and the pre-v7 observation design. Anything
> here is superseded by [`../CURRENT_PLAN.md`](../CURRENT_PLAN.md) and
> [`../ITERATION_HISTORY.md`](../ITERATION_HISTORY.md), which win in any disagreement.

# Design Iterations: Reward Shaping and Observation Vector

## Framework: SB3 PPO → SampleFactory APPO

Early training runs (PPO v1–v6) used Stable-Baselines3 synchronous PPO. After the curl-cheat fix reached 85% mean progress, the switch to SampleFactory APPO was made to accelerate further iteration — faster rollout throughput meant reward and observation changes could be evaluated in hours rather than days. All subsequent runs (APPO v7 onward) use SF.

Beyond raw speed, the architectural differences were meaningful for this environment:

**Async rollout/train overlap.** In synchronous PPO the GPU sits idle while workers step environments, then all workers sit idle while the GPU runs a gradient update. SF decouples the two: CPUs are continuously stepping environments and the GPU is continuously running inference and training. Neither idles waiting for the other.

**80 truly parallel environments without GIL contention.** Each of the 40 rollout workers is a separate process with CPU core affinity pinned, giving 80 concurrent environment instances (40 workers × 2 envs per worker). SB3 vectorised environments share a single Python process and therefore a single GIL. MuJoCo physics stepping and depth rendering are CPU-bound, so eliminating that contention directly increases throughput.

**Policy lag tolerance.** Workers can run a small number of updates behind the latest policy weights (`max_policy_lag = 1000`). There is no hard synchronisation barrier, so a worker handling a geometrically complex colon seed that takes longer to step does not stall the rest of the pipeline.

**Native GRU support with correct BPTT.** SF treats the rollout window as the backpropagation-through-time window (`rollout = recurrence = 64`). This is important here because the task is partially observable — the GRU must integrate depth frames across haustral ring approaches to build a sense of lumen direction. SB3's recurrent policy support is less tightly integrated and harder to configure correctly for this use case.

---

## Final reward function

```
r = W_PROGRESS × new_territory × (0.3 + 0.7 × (1 − force_norm))
  − W_TIP_PENALTY  [if tip disk in wall contact]
  − W_STUCK_PENALTY  [terminal, if episode ends with no progress]
```

| Constant | Value | Role |
|---|---|---|
| `W_PROGRESS` | 2.0 | Scales new-territory advance reward |
| `W_TIP_PENALTY` | 0.001 / step | Dense penalty while tip disk presses wall (UFO posture) |
| `W_STUCK_PENALTY` | 0.05 | Terminal penalty for no-progress truncations |
| `MAX_INSERTION_FORCE` | 30 N | Calibrated contact-force ceiling (see below) |

### Key terms

**`new_territory`** — `max(0, actual_base_s − max_actual_base_s)`. Only the first time the scope reaches a given depth earns reward. Re-advancing over already-covered ground earns nothing. This prevents oscillation farming (advance → retreat → advance) which naive `Δs` rewards allow.

**`force_norm`** — `clip(Σ ‖contactForce_i‖ / 30 N, 0, 1)`. The 30 N ceiling was calibrated empirically: a straight gentle advance peaks at ~0.17 N (`force_norm ≈ 0.006`); the curl cheat peaks at ~215 N (`force_norm >> 1`, instant termination). Values between 0 and 1 scale the progress reward continuously — this matters (see iteration 4 below).

**Force multiplier `(0.3 + 0.7 × (1 − f))`** — a soft ramp, not a hard gate. A clean advance earns ~99% credit; a high-contact-but-not-terminal advance earns ≥30% credit (gradient floor). The floor is load-bearing: without it the policy loses gradient signal entirely at wall contact and cannot learn to steer away.

**`tip_contact` obs bit** — a 0/1 flag appended to the state vector indicating whether the tip disk is in contact with the colon wall. This was added after training revealed a sideways-press exploit (see iteration 6) and gives the policy a direct signal to act on.

**Episode termination** — `force_norm ≥ 1.0` (extreme curl) or `actual_base_s < base_s_init` (ejected). **Truncation** — no new territory in `STUCK_WINDOW` steps, or tip in continuous contact for `TIP_STUCK_WINDOW = 50` steps. Truncations use bootstrap value (not zero-value terminal); treating them as terminations collapses training by penalising reaching any obstacle.

---
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

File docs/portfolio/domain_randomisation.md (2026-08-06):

> ⚠️ **Harvested 2026-08-06 from the v6_dr portfolio snapshot (`colonoscope-rl`, last touched
> 2026-06-30). NOT yet refreshed for v8_p1.** It describes the kinematic-base v6 line — no
> physical flexible shaft, no roller/capstan feeder, and the pre-v7 observation design. Anything
> here is superseded by [`../CURRENT_PLAN.md`](../CURRENT_PLAN.md) and
> [`../ITERATION_HISTORY.md`](../ITERATION_HISTORY.md), which win in any disagreement.

# Domain Randomisation
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

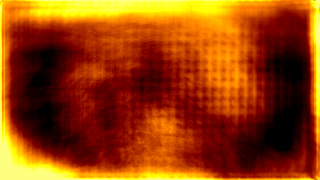
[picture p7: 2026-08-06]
perception/rd_v2/error_map_vis.png

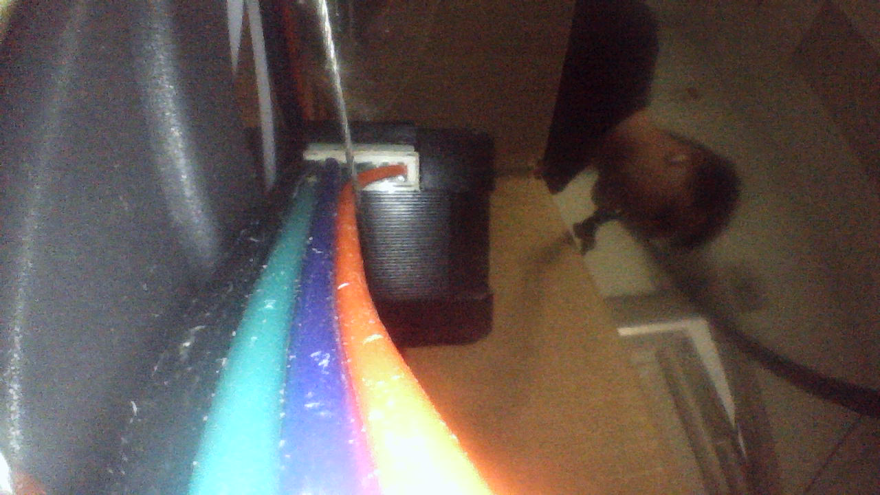
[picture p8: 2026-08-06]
perception/realtime/sample_frame.png

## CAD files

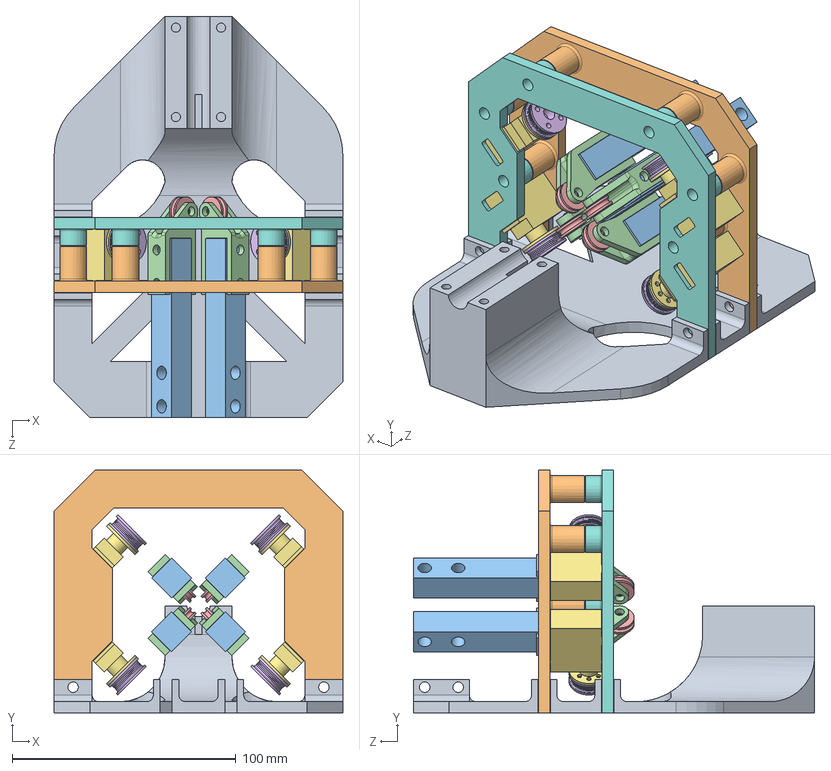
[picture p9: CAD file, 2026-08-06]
hardware/cad/Full assem.SLDASM
129.2 x 108.6 x 179.4 mm
sts3032 Bracket male
sts3032 x 4
Spool x 4
bearing wheel x 4
Pulley x 4
Load cell block x 4
sts3032 Bracket Female
shaft clamp

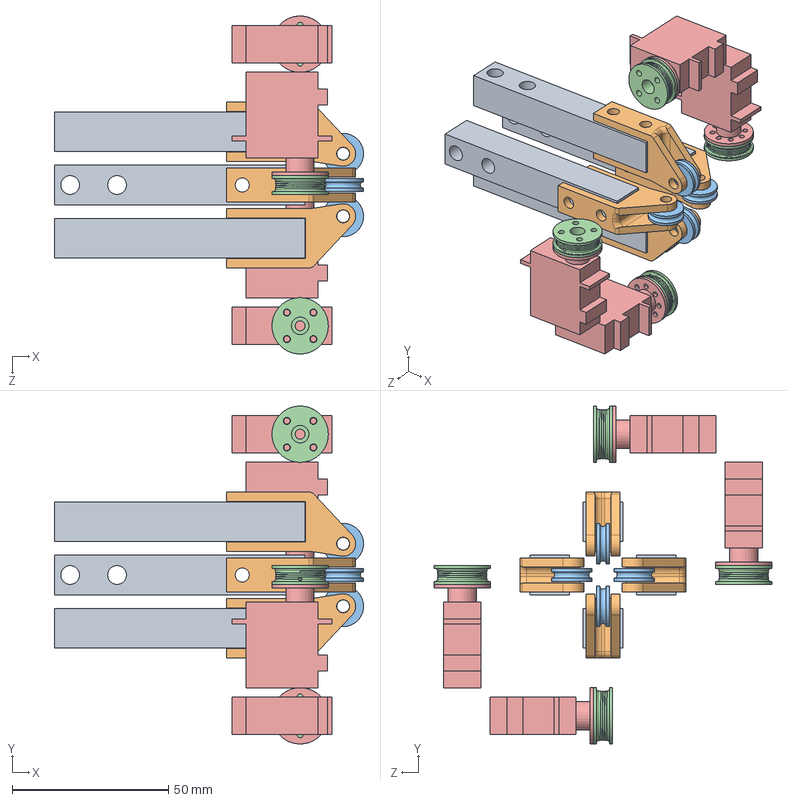
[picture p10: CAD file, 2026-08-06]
hardware/cad/Layout Assembely.SLDASM
98.8 x 108.0 x 108.0 mm
sts3032 x 4
Spool x 4
bearing wheel x 4
Pulley x 4
Load cell block x 4

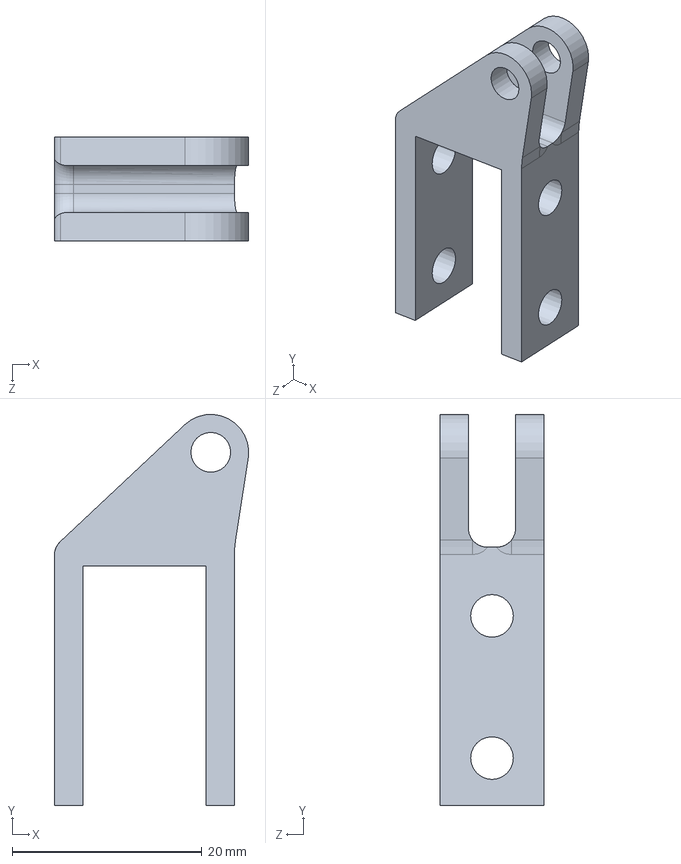
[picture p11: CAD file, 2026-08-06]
hardware/cad/Pulley.SLDPRT
20.5 x 41.2 x 11.0 mm

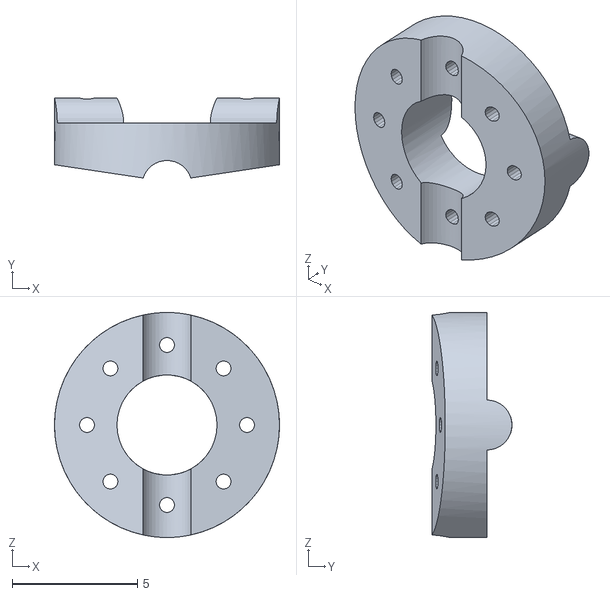
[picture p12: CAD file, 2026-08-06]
navigation/v6_dr/new8.stl
9.00 x 3.20 x 9.00

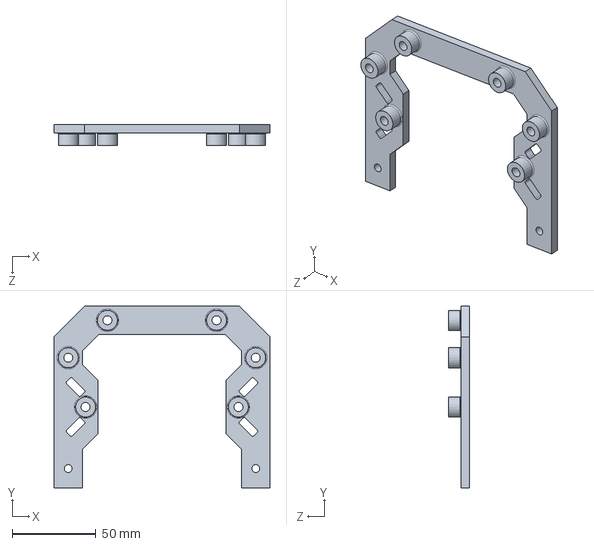
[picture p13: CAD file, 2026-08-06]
hardware/cad/sts3032 Bracket male.SLDPRT
129.2 x 108.6 x 12.5 mm

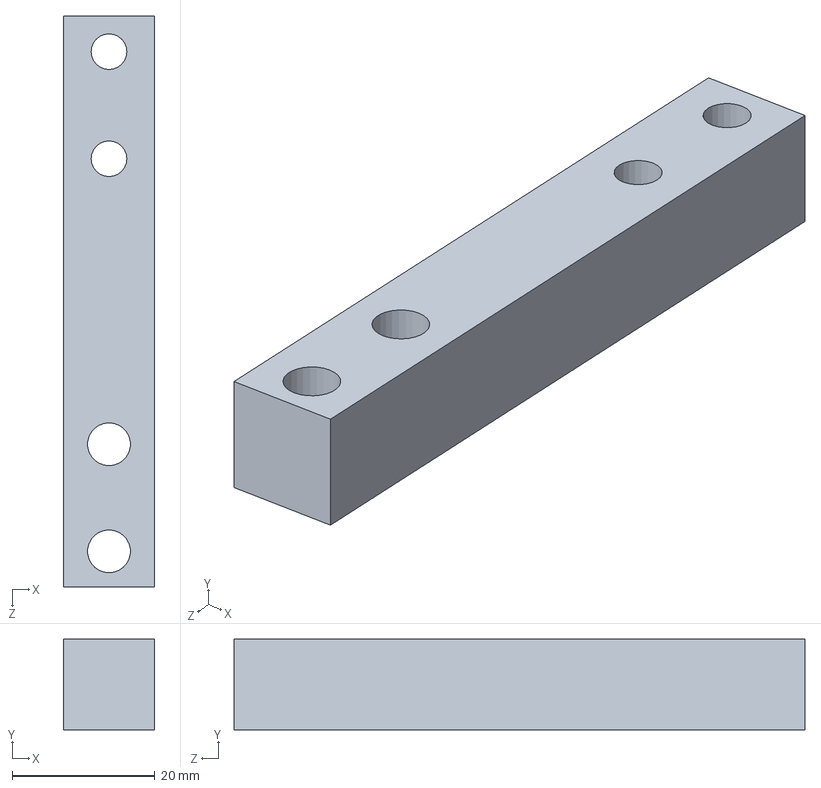
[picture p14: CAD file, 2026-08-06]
hardware/cad/Load cell block.SLDPRT
12.7 x 12.7 x 80.0 mm

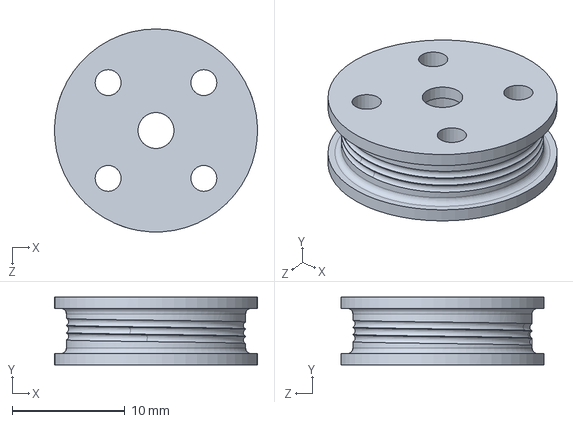
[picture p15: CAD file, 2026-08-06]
hardware/cad/Spool.SLDPRT
18.0 x 6.02 x 18.0 mm

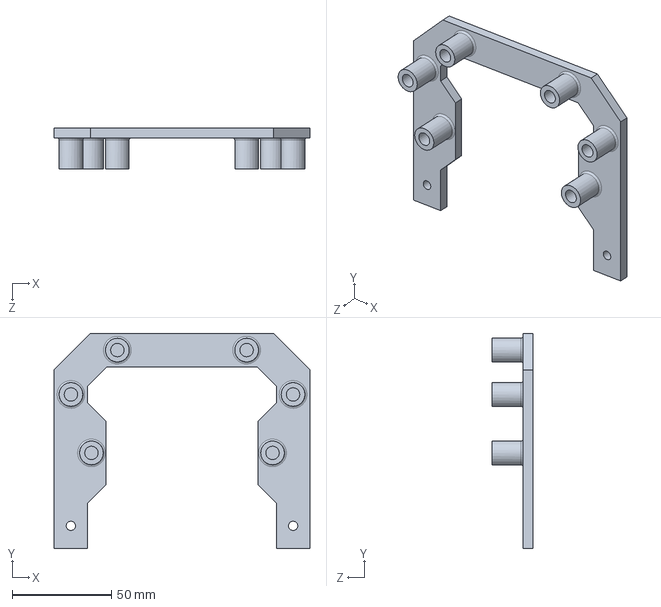
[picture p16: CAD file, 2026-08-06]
hardware/cad/sts3032 Bracket Female.SLDPRT
129.2 x 108.6 x 20.5 mm

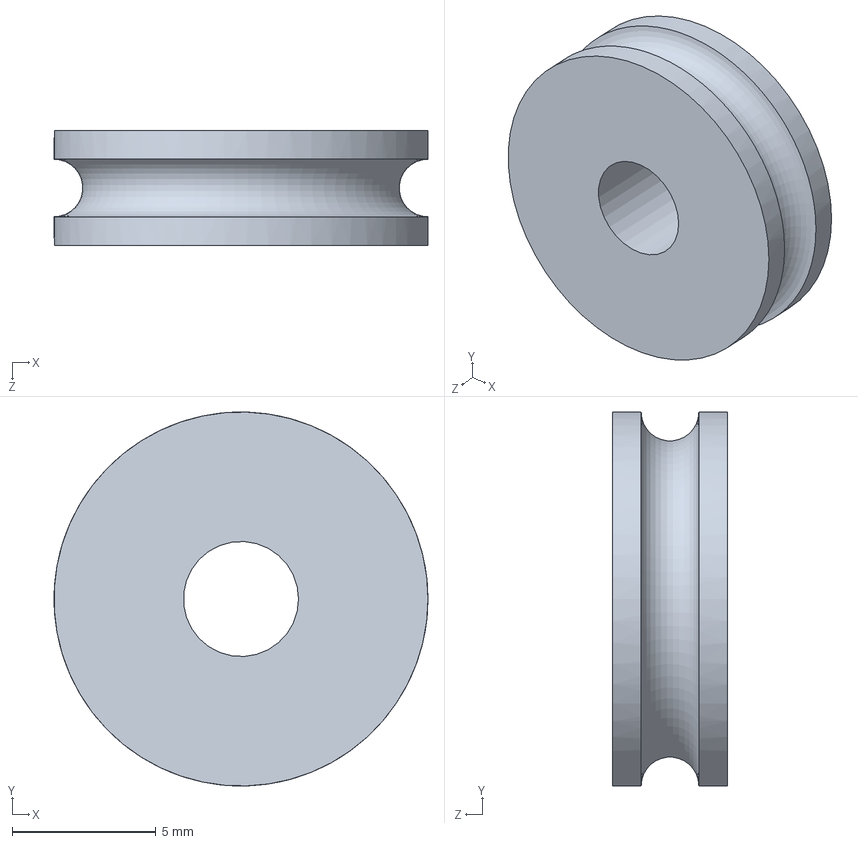
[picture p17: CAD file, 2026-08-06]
hardware/cad/bearing wheel.SLDPRT
13.0 x 13.0 x 4.00 mm

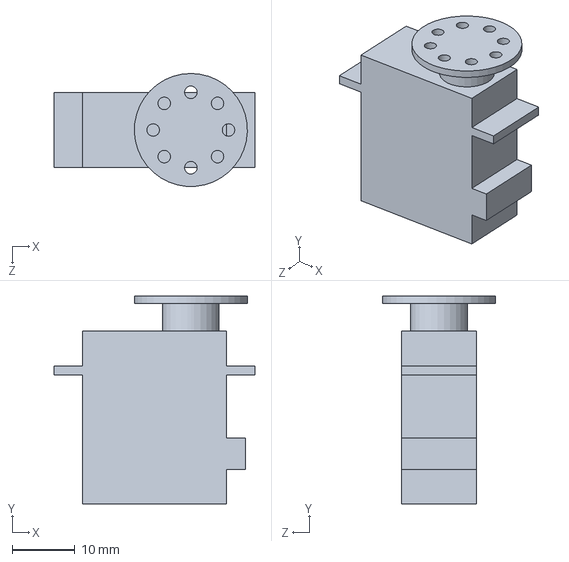
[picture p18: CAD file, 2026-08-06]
hardware/cad/sts3032.SLDPRT
32.0 x 33.1 x 18.0 mm

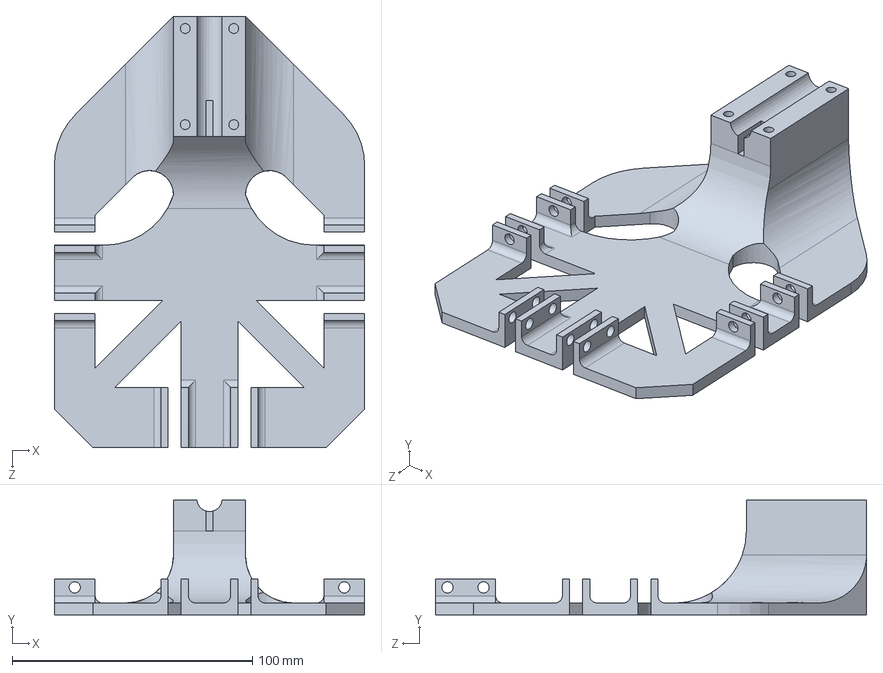
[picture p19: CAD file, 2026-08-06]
hardware/cad/shaft clamp.SLDPRT
129.2 x 47.9 x 179.4 mm

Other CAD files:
hardware/cad/Cantilever bracket.SLDPRT
hardware/cad/shaft clamp top.SLDPRT
hardware/cad/Full assem.STL

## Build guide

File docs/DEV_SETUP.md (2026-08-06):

# Development setup

Everything needed to *run* this repo: interpreters, machines, sync rules, and the commands
that work. Moved out of the top-level README on 2026-08-06 so that README could serve a
first-time reader; this is the operational reference for whoever is actually working on it.

For **where the project is and what happens next**, see [CURRENT_PLAN.md](CURRENT_PLAN.md) —
the single source of truth.

---

## Interpreter matrix (Windows)

| Interpreter | Use for | Has |
|---|---|---|
| `C:\Python314\python.exe` | **`navigation/` scripts that don't import sample_factory** — `view_colon_seed.py`, `manual_test.py`, and the env itself | mujoco 3.8.1, CPU torch. **`eval_sf.py`/`viewer_sf.py` cannot run here** — Python 3.14 lacks `signal-slot-mp`, so the sample_factory import chain fails. Use the WSL2 mirror. |
| `C:\Users\lukec\AppData\Local\Programs\Python\Python311\python.exe` | **All `perception/` scripts** | CUDA torch (RTX 4060), transformers, editable depth-anything-3 from `C:\Users\lukec\PycharmProjects\Depth-Anything-3` (do not delete that repo) |
| Blender 5.1 (`C:\Program Files\Blender Foundation\Blender 5.1\blender.exe`) | perception dataset regeneration only | headless Cycles GPU (OPTIX) |

Training itself runs on the remote native-Linux rig (40 workers, GPU rendering), not on
Windows. `train_sf.py` defaults `MUJOCO_GL=egl` (Linux); a Windows smoke test needs
`$env:MUJOCO_GL='wgl'` set first.

---

## Machines

| Machine | Role |
|---|---|
| Windows workstation | Development, scene generation, all perception work |
| Native-Linux training rig | **Where training actually happens.** Not reachable from the dev machine — training is never launched automatically. |
| WSL2 (Ubuntu-22.04) mirror at `~/mujoco_v3/` | Eval and viewing of rig-trained checkpoints **only** — never training. Exists because `eval_sf.py`/`viewer_sf.py` do not run on Windows. |

---

## Multi-machine sync

`navigation/v8_p1/` is the single sync unit for the Linux rig, and must stay a self-contained
one-folder bundle (its own scope generator, `new8.stl`, `error_map_64.npy`). **No auto-sync
exists** — copies drift silently the moment one is edited alone. After editing here, re-copy
the whole folder (minus `scenes/`, `runs_sf/`, `__pycache__/`) and verify on the far side.

The WSL2 mirror reproduces this repo's layout, so the sync is a plain folder-to-folder copy:

```bash
# from Windows, into WSL
rsync -a --exclude 'scenes/' --exclude '__pycache__/' \
  /mnt/c/Users/lukec/PycharmProjects/Mujuco_V3/navigation/v8_p1 \
  ~/mujoco_v3/navigation/
```

⚠️ **Think before adding `--delete`.** The WSL mirror can be the *only* copy of a checkpoint
Sample Factory has already rotated out of the rig's `checkpoint_p0/` — `--delete` will take it
with it. This has happened once, on 2026-07-13: it removed the last surviving copies of
v8_p1_v1's pre-fix `reward_0.440` best checkpoint.

The WSL venv is `~/mujoco_v3/.venv` (Python 3.10, mujoco 3.10.0, torch cu130). Include
`runs_sf/` in the copy when you want to view a new checkpoint.

---

## Commands

### Windows

```powershell
# View a generated colon (regenerates scenes\ automatically)
C:\Python314\python.exe navigation\v8_p1\view_colon_seed.py --seed 0

# Manually drive the shaft/roller model — INTERACTIVE, opens a MuJoCo viewer window
# and waits for keypresses (arrows bend the tip, Shift/Ctrl feed and retract).
# It is NOT headless and never exits on its own — run it yourself, don't script it.
C:\Python314\python.exe navigation\v8_p1\manual_test.py --seed 0
```

### WSL2 — eval and viewer

**`eval_sf.py` and `viewer_sf.py` do not run on Windows** (Python 3.14 is missing
`signal-slot-mp`, so the sample_factory import chain fails).

```bash
cd ~/mujoco_v3/navigation/v8_p1
~/mujoco_v3/.venv/bin/python eval_sf.py --seed 0 --episodes 1 --workers 1
~/mujoco_v3/.venv/bin/python viewer_sf.py --seed 0
```

⚠️ **Do not prefix these with `MUJOCO_GL=egl`.** Each script already picks the right backend,
and an inherited `MUJOCO_GL` overrides that choice in both:

- `eval_sf.py` defaults to **osmesa** (CPU). Under WSL2's GPU paravirtualisation every depth
  render becomes a high-latency round-trip, so egl is ~7× slower (~179 ms/env-step vs ~24 ms)
  and leaves CPU *and* GPU idling at ~15%. Pass `--gl egl` only on the native rig, where it
  does win.
- `viewer_sf.py` needs **glfw** to open a window at all — forcing egl gives you a headless
  backend and no viewer.

`viewer_sf.py` runs the policy **deterministically by default** (the Gaussian's mean, i.e. what
you would deploy). It previously sampled, which is *training* mode — with the policy's learned
σ ≈ 0.627 on a ±1 action space, that made the tip look violently unstable when it is not. Pass
`--stochastic` for the old behaviour.

WSLg's GUI can go unresponsive; `wsl --shutdown` from Windows fixes it.

---

## CAD — refreshing `hardware/cad/`

The SolidWorks working copy lives **outside the repo**, at
`C:\Users\lukec\Documents\Solidworks Projects\Endoscope`. `hardware/cad/` is a published copy and
goes stale when the design moves. To refresh it:

1. Open **`Full assem.SLDASM`** in the working folder.
2. `File → Pack and Go` — it resolves the reference tree, so live parts never have to be
   identified by hand. Tick **"Include suppressed components"** if any exist.
3. Click **`Add File...`** and add **`Layout Assembely.SLDASM`**.
4. Tick **"Flatten to single folder"**.
5. **Save to folder** → `hardware\cad`. Not "Save to Zip file". The original is copied, never
   moved.
6. Close everything, reopen from `hardware\cad`, and check the FeatureManager tree for
   unresolved-component flags. `File → Find References` confirms nothing still resolves back to
   `Documents\`.
7. Re-export `Full assem.STL` — `File → Save As → STL → Options`, with **"Save all components of
   an assembly in a single file"** ticked. A stale STL next to fresh sources is worse than none.

⚠️ **Do not run Pack and Go twice into the same folder.** Both assemblies share parts. A second
run collides with files the first wrote, leaving per-file overwrite decisions — and one wrong
call leaves the two assemblies pointing at *different copies of the same part*. One operation
with both files packages the union of their references once, consistently.

The 2026-08-06 port carried 10 of 16 source parts. The 6 left behind were superseded iterations:
`mg996r` and `Servo holding block` (the design moved to STS3032 serial servos), `Shaft ring`,
`Spool helic reverse`, `Spool_testing`, and the single `sts3032 Bracket` replaced by the
male/female pair. The source folder's `STL/` directory is print history and was deliberately not
copied.

---

## Generated output

`scenes/` folders are always regenerated on demand — safe to delete at any time. Scene XML is
**never cached across runs** (`build_scene()` always regenerates), so a physics or generator
edit cannot be silently masked by a stale scene.

---

## Version control

The project has been under git since 2026-08-06, on `main`, pushed to the **private** GitHub
repo `luke-crompton/Autonomous-Endoscope-Navigation-Mujoco`. `core.autocrlf` is set to `false`
locally so tracked files stay byte-identical to the Linux rig and WSL2 copies.

**git does not cover everything.** `.gitignore` excludes trained checkpoints (`*.pth`),
`scenes/`, `.summary/` TensorBoard events, perception datasets and `__pycache__/`. Those have
no history and no remote copy — deleting one is still permanent. Checkpoints cannot go into git
at all (`da3small_finetune_head.pth` is 131 MB, over GitHub's 100 MB hard limit); publish them
as GitHub Release assets instead.

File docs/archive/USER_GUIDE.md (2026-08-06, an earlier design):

> ## ⚠️ SUPERSEDED — HISTORICAL ARCHIVE, DO NOT FOLLOW
> This document describes the **old Mujuco_V2 layout** (`Stage4/vN/`, `transfer/`,
> `Perception/`). Those paths no longer exist in this project, and many of the datasets,
> checkpoints, and CNN weights it references have been deleted. **Do not use it for
> commands, file paths, or "how to run" instructions.**
> - To run something: see the root `README.md`.
> - For the project's history and design rationale: see `../ITERATION_HISTORY.md`.
>
> Kept verbatim only as a record of what was written at the time. Nothing here should be
> edited or acted on.

# User Guide — Mujuco_V2 (Simulated Videoscope Navigation)

A practical "how to run it / what each file does" guide for the repository. For the
*story* of what was built and why (results, design decisions), see `REPORT.md` and
`PROJECT_CONTEXT.md`. This guide is the operational complement.

**Authorship note.** Two parts of this repo were **provided by my supervisor** and are
marked *(supervisor-provided)* below — `Videoscopesimulations/` (the scope tip) and
`colon_realistic_geometry_handoff_2026-05-26/` (the photorealistic Blender colon).
Everything else (my procedural colon, the CNNs, the Stage 4 V1 loop, the DA3 fine-tune,
and the collision RL pipeline) is my own work.

---

## 1. Environment & prerequisites

This project uses **two different Python interpreters** — using the wrong one is the
single most common mistake.

| Purpose | Interpreter | Notes |
|---|---|---|
| **All training / inference / RL** | `C:\Users\lukec\AppData\Local\Programs\Python\Python311\python.exe` | Python 3.11.1. Has GPU `torch` (CUDA, RTX 4060), Stable-Baselines3, Gymnasium, Depth-Anything-3. **Use this for everything.** |
| (avoid) | `python` on PATH | Python 3.14, **CPU-only torch** — silently slow / wrong for training. Do not use. |

Other dependencies:

- **Blender 5.1** — `C:\Program Files\Blender Foundation\Blender 5.1\blender.exe`
  (use `blender.exe`, **not** `blender-launcher.exe`). Needed only for the
  photorealistic colon renders.
- **Depth-Anything-3 source** — editable install at
  `C:\Users\lukec\PycharmProjects\Depth-Anything-3`. Do not delete; the DA3 scripts
  import from it.
- **Pandoc** (optional) — installed; converts `REPORT.md`/this guide to HTML/Word if
  wanted.

> **Tip:** in the examples below, `$PY311` stands for the 3.11 interpreter. Set it once
> per PowerShell session:
> ```powershell
> $PY311 = "C:\Users\lukec\AppData\Local\Programs\Python\Python311\python.exe"
> ```

**Constraint:** Depth-Anything-3 pins Python `>=3.9, <=3.13`, so do not upgrade the 3.11
interpreter past 3.13 for DA3 work.

---

## 2. Datasets are not in the repo (regenerable)

To keep the project small, the large training datasets and inference outputs were
**deleted** — they are all regenerable from the scripts here. If a script complains a
folder is missing, regenerate it (see §4 workflows):

| Deleted folder | Regenerate with |
|---|---|
| `Perception/depth_regression/depth_dataset/` | `Depth_dataset.py` (workflow C) |
| `Perception/realistic_depth_field/dataset_finetune/` | `blender_depth_dataset.py` (workflow E) |
| `Perception/realistic_depth_field/dataset/` (pilot) | `blender_depth_dataset.py` |
| `Perception/realistic_depth_field/predictions*/` | `run_da3_inference.py` (workflow F) |

Trained models (`*.pth`, PPO `*.zip`) and run videos **are** kept.

---

## 3. Repository map

| Folder | What it is |
|---|---|
| `Perception/` | My procedural colon model + the perception CNNs + the DA3 depth work. |
| `Perception/depth_regression/` | "Deepest depth blob" steering CNN + its dataset generator. |
| `Perception/centreline_regression/` | Centreline-based steering CNNs, incl. `look_ahead_10mm/` (**current best**) and `look_ahead_15mm/` (superseded). |
| `Perception/realistic_depth_field/` | DA3-SMALL fine-tune + inference + the (dropped) Blender-in-the-loop nav test. |
| `Videoscopesimulations/` | *(supervisor-provided)* the 25-hinge tendon-driven scope tip. |
| `Stage4/v1/` | My working **collision-free** closed-loop controller (the V1 baseline). |
| `Stage4/v2_collision/` | My **collision-enabled RL** pipeline (current frontier). |
| `colon_realistic_geometry_handoff_2026-05-26/` | *(supervisor-provided)* photorealistic Blender colon code; I added `blender/blender_depth_dataset.py` for the DA3 dataset. |

---

## 4. Common workflows (copy-paste)

### A. Run the Stage 4 V1 closed loop (the headline demo)
Drives the scope through my colon using the best steering CNN, opens the MuJoCo viewer +
a camera overlay, and logs annotated frames.
```powershell
& $PY311 "Stage4\v1\controller_loop.py"
# then compact the frames into a timestamped video:
& $PY311 "Stage4\v1\frames_to_video.py"
```
To switch perception model, edit `CNN_FLAVOUR` near the top of `controller_loop.py`
(default `"centreline_10mm"`; options listed in the file).

### B. Train a PPO collision policy
Edit the run constants near the top of `train_ppo.py` first (`RUN_NAME`, `N_ENVS`,
`ent_coef`, etc.), then:
```powershell
& $PY311 "Stage4\v2_collision\train_ppo.py"                 # full run (TOTAL_TIMESTEPS)
& $PY311 "Stage4\v2_collision\train_ppo.py" --smoke         # short smoke + resource report
& $PY311 "Stage4\v2_collision\train_ppo.py" --total_timesteps 500000
```
Use **8 vec envs** (strictly safe on 16 GB RAM); 10 is tolerable; 12 pages to disk.
A 1M-step run is ~75 min on the RTX 4060. Output → `Stage4/v2_collision/runs/<RUN_NAME>/`.

### C. Evaluate / watch a PPO checkpoint
```powershell
& $PY311 "Stage4\v2_collision\eval_ppo.py" --model "Stage4\v2_collision\runs\ppo_v6_entcoef015\final.zip" --episodes 10
& $PY311 "Stage4\v2_collision\viewer_ppo.py"     # live MuJoCo viewer (set checkpoint near top of file)
```
> Note: the kept checkpoints `ppo_v3` and `ppo_v6` both *cheated* (see REPORT.md §5) —
> useful to watch, **not** honest baselines.

### D. Regenerate the steering-CNN dataset, then train
```powershell
& $PY311 "Perception\depth_regression\Depth_dataset.py" --n_samples 2000 --seed 2
& $PY311 "Perception\depth_regression\Training_point_regression.py"          # depth-blob CNN
& $PY311 "Perception\centreline_regression\look_ahead_10mm\relabel_centreline.py"   # re-derive 10mm labels (no re-render)
& $PY311 "Perception\centreline_regression\look_ahead_10mm\Training_centreline_regression.py"
```

### E. Render the photorealistic colon dataset (Blender, GPU)
```powershell
$BLENDER = "C:\Program Files\Blender Foundation\Blender 5.1\blender.exe"
& $BLENDER --background --python "colon_realistic_geometry_handoff_2026-05-26\blender\blender_depth_dataset.py" -- `
    --output "Perception\realistic_depth_field\dataset_finetune" --total 1500 --samples 32
# then drop void/wall-clip frames (dry-run first, then --apply):
& $PY311 "Perception\realistic_depth_field\filter_void_frames.py" --dataset_dir "Perception\realistic_depth_field\dataset_finetune"
& $PY311 "Perception\realistic_depth_field\filter_void_frames.py" --dataset_dir "Perception\realistic_depth_field\dataset_finetune" --apply
```

### F. Fine-tune DA3 and run inference
```powershell
& $PY311 "Perception\realistic_depth_field\finetune_da3.py" --batch_size 16 --epochs 20
& $PY311 "Perception\realistic_depth_field\run_da3_inference.py" `
    --checkpoint "Perception\realistic_depth_field\checkpoints\da3small_finetune_head.pth" `
    --output_dir "Perception\realistic_depth_field\predictions_finetune" --save_vis
```
(`run_da3_inference.py` without `--checkpoint` runs zero-shot DA3.)

---

## 5. File-by-file reference

Main files get a full description; helpers are one-liners.

### `Perception/` (root)
- **`Colon_mesh_xml.py`** — *(main)* My procedural colon generator. Builds the 500 mm
  anatomical centreline (ascending → flexures → descending), a ~15 mm-radius tube with
  35 haustral folds and a soft 3-lobed cross-section, and writes `colon.obj`,
  `colon_centreline.csv`, and `colon_test.xml` (pink material + endoscope tip light).
  Exposes `build_frames()` for camera placement. Seeded by `FOLD_SEED` for
  reproducibility. Everything downstream consumes its outputs.
- `Colon viewr.py` — one-off MuJoCo viewer for the colon mesh.
- `view_test.py` — renders 4 fixed camera views to sanity-check the camera maths.

### `Perception/depth_regression/`
- **`Depth_dataset.py`** — *(main)* Dataset generator. Picks random centreline points,
  perturbs the camera pose, moves the tip light to the camera, renders RGB + depth, and
  computes **two** labels per frame: deepest-depth-blob (`target_x/y`) and
  deepest-visible-centreline (`target_centre_x/y`). Writes `labels.csv` + RGB + depth
  `.npy` + debug overlays to `depth_dataset/`. CLI: `--n_samples`, `--seed` (default 2),
  `--out_dir`, `--width/--height`, plus pose-perturbation ranges. Run with `--help` to
  see all.
- **`Training_point_regression.py`** — *(main)* Trains a ResNet-18 (ImageNet-pretrained,
  head → `Linear→ReLU→Linear(2)→Tanh`) on `target_x/y`. 80/20 split, 30 epochs, Adam,
  MSE. Writes `colon_target_cnn.pth`.
- `Testing_point_regression.py` — loads weights, plots true vs predicted on a random
  frame.

### `Perception/centreline_regression/`
- **`Training_centreline_regression.py`** — *(main)* Same architecture as the
  depth-flavour trainer but reads `target_centre_x/y` (deepest-visible centreline).
  Writes `colon_centreline_cnn.pth`. **Superseded** by the look-ahead variants.
- `Testing_centreline_regression.py` — sibling tester.
- **`look_ahead_10mm/`** — *(main, current best)* Self-contained 10 mm pure-pursuit
  variant: `relabel_centreline.py` (re-derives labels from saved camera quats + depth,
  no re-render), its own `Training_/Testing_centreline_regression.py`, and trained
  `colon_centreline_cnn.pth`. This is the model the V1 loop uses.
- `look_ahead_15mm/` — same pattern at 15 mm; **superseded** (clipped walls at flexures).

### `Perception/realistic_depth_field/` (the DA3 work)
- **`finetune_da3.py`** — *(main)* Head-only fine-tune of DA3-SMALL (freezes the DinoV2
  backbone + cam enc/dec; trains only the ~11% DualDPT depth head). Mixed loss
  (scale-invariant log + `--metric_weight`×L1-in-metres). CLI: `--dataset_dir`,
  `--epochs` (20), `--batch_size` (default 4; the documented run used **16**), `--lr`,
  `--metric_weight` (0.1), `--seed`. Writes `checkpoints/da3small_finetune_head.pth`.
- **`run_da3_inference.py`** — *(main)* Runs DA3 (zero-shot, or fine-tuned via
  `--checkpoint`) over a dataset, saving predicted depth/conf, optional `RGB|pred|GT`
  vis (`--save_vis`), and `summary.json` (raw + scale-aligned MAE, GT/pred ratio). CLI:
  `--dataset_dir`, `--output_dir`, `--checkpoint`, `--limit`, `--device`, `--save_vis`.
- **`filter_void_frames.py`** — drops frames that are mostly black (rays missing into
  void). Dry-run by default; pass `--apply` to actually move files + rewrite `poses.npy`.
  CLI: `--dataset_dir`, `--threshold` (0.10).
- `test_navigation.py` — *(main, but dropped)* the hybrid MuJoCo+Blender nav test
  (depth-centroid aim + PD). Kept as reusable infrastructure; did **not** traverse
  reliably (no collisions). CLI: `--seed`, `--max_steps`, `--samples`, `--checkpoint`,
  `--out_dir`.
- `build_nav_scene.py` — generates the scope-only MuJoCo XML for `test_navigation.py`
  (Blender renders the colon, MuJoCo only does scope physics).
- `blender_render_worker.py` — persistent Blender subprocess (stdin JSON pose → render);
  driven by `test_navigation.py`, not run directly.

### `Videoscopesimulations/` *(supervisor-provided)*
- **`generate_videoscope_one_section.py`** — XML builder for the scope tip: 26 disks,
  25 alternating-axis hinges, 4 tendons + 4 actuators. Imported by both Stage 4 folders.
- `manual_tendon_viewer.py` — interactive viewer with antagonistic tendon control.
- `videoscope_one_section.xml`, `new8.stl`, `README.md` — generated model + mesh + the
  folder's own run notes.

### `Stage4/v1/` (my collision-free baseline)
- **`controller_loop.py`** — *(main)* The closed loop: regenerate scene → load CNN →
  per step render tip-cam → CNN inference → pixel error → rate-limited proportional
  tendon update → advance base along centreline → physics step. Writes annotated frames
  + `run_output/control_log.csv`. **No CLI** — tune via constants at the top
  (`CNN_FLAVOUR`, `K_P`, `RATE_MAX`, `DEADZONE`, `ADVANCE_RATE_M_PER_STEP`, `SIGN_X/Y`).
- **`build_combined_scene.py`** — *(main)* Generator that writes `combined_scene.xml`:
  places the scope inside my colon, sets the base mocap, adds `tip_cam`/`tip_light`.
  Called by the loop; can be run standalone to regenerate the scene.
- `frames_to_video.py` — compacts `run_output/frames/*.png` into a timestamped MP4
  (`--output x.gif` for GIF, `--delete` to remove PNGs).

### `Stage4/v2_collision/` (my collision RL pipeline)
- **`scope_colon_env.py`** — *(main)* The Gymnasium env `ScopeColonEnv`. Action
  `Box(-1,1,(3,))` = two tendon-pair commands + base advance. Observation = depth image
  `(1,64,64)` + small state vector. Reward = progress (high-water-marked) + goal −
  collision + waypoints. **Note:** the aim/look reward machinery from the v7 experiments
  is still present here and is slated for removal in the reframe (see REPORT.md §6).
- **`build_collision_scene.py`** — *(main)* Scene XML generator: visual mesh +
  per-triangle prism collision + scope + mocap target + tip cam/light. CLI:
  `--seed N`. Returns `(xml_path, centreline)`.
- **`colon_generator.py`** — *(main)* Pure-NumPy procedural colon (a port of the
  supervisor's Blender `random_centerline`+`build_tube`). One seed → high-res visual
  STL + low-res collision STL.
- **`mesh_to_thin_prisms.py`** — *(main)* Turns each wall triangle into a thin extruded
  6-vertex prism `<geom>` so a hollow tube collides correctly (the default convex-hull
  mesh would be a solid blob).
- **`train_ppo.py`** — *(main)* SB3 PPO `MultiInputPolicy` (NatureCNN on depth + MLP on
  state), `SubprocVecEnv`. CLI: `--smoke`, `--total_timesteps`, `--single_env`. Run
  constants (`RUN_NAME`, `N_ENVS`, `ent_coef`, reward weights) are edited at the top.
- **`eval_ppo.py`** — *(main)* Loads a checkpoint, runs N deterministic episodes per
  seed, prints a per-seed completion table. CLI: `--model`, `--episodes`, `--seeds`.
- `viewer_ppo.py` — live MuJoCo viewer + cv2 depth window for a checkpoint (watch for
  cheats).
- `view_scene.py` — viewer for the benchmark scenes without a policy (set `SCENE` at top).
- `baselines.py` — random / forward / centre-on-depth scripted policies for reference.
- `benchmark_collisions.py`, `_check_stl_axis.py`, `_smoketest_env.py`,
  `_smoketest_viz.py` — early-session benchmark/smoke helpers.
- `runs/` — PPO checkpoints. `ppo_v6_entcoef015/final.zip` (85% but cheated),
  `ppo_v3/final.zip` (66% but cheated), plus failed v1/v2/v4/v5/v7* runs kept for
  progress review.

### `colon_realistic_geometry_handoff_2026-05-26/` *(supervisor-provided)*
- `blender/blender_depth_dataset.py` — *(my derivative)* the DA3 dataset generator I
  wrote on top of the supervisor's Blender colon (adds intrinsics/pose dumps + GPU
  device enable). CLI (after `--`): `--output`, `--total`, `--samples`, `--width/height`.
- Other `blender/`, `mujoco/`, `colon3d/` files — supervisor's colon-generation and
  rendering code. Treat as a provided library.

---

## 6. Key artifacts on disk

| File | What |
|---|---|
| `Perception/centreline_regression/look_ahead_10mm/colon_centreline_cnn.pth` | Best steering CNN (used by V1 loop). |
| `Perception/depth_regression/colon_target_cnn.pth` | Depth-blob steering CNN. |
| `Perception/realistic_depth_field/checkpoints/da3small_finetune_head.pth` | Fine-tuned DA3 depth model (val MAE 3.28 mm, metric). |
| `Stage4/v2_collision/runs/ppo_v6_entcoef015/final.zip` | 85% PPO policy — **cheated**, evidence only. |
| `Stage4/v1/run_output/*.mp4` | Closed-loop run videos. |

---

## 7. Gotchas

- **Wrong Python** is the #1 trap — always use the 3.11 interpreter for torch/RL/DA3.
- **RAM** on the 16 GB laptop: 8 PPO vec envs safe, 12 pages to disk.
- **Viewer lighting affects the camera:** the MuJoCo passive viewer and the offscreen
  renderer share lighting state, so toggling the viewer headlight changes what the
  tip-cam (and thus the CNN) sees. Don't change viewer lighting during a controlled run.
- **Cheated checkpoints** (`ppo_v3`, `ppo_v6`) score well but are not honest baselines.
- **Datasets are absent by design** (§2) — regenerate rather than assuming a path exists.

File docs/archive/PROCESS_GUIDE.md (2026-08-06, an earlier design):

# Process Guide

This guide defines how Claude should work in this project.  
Claude should act as a careful pair programmer, not an autonomous agent.

## Core Principle

Do not make assumptions, large edits, or background changes without approval.  
Prefer small, reviewable, reversible changes.

---

## Default Behaviour

- Do not edit files unless explicitly asked.
- Do not make code changes before explaining the plan.
- Do not make broad refactors unless specifically requested.
- Do not change unrelated files.
- Do not delete code unless explicitly approved.
- Do not rename files, functions, classes, variables, or modules without approval.
- Do not change public APIs, function signatures, input formats, or output formats without approval.
- Do not install, remove, or update packages without approval.
- Do not change project configuration without approval.
- Do not modify tests just to make broken code pass.
- Do not claim something works unless it has been run or clearly explain that it has not been tested.

---

## Before Editing Code

Before making any file changes, provide:

1. What you think the task is
2. The files you believe are relevant
3. A list of possible approaches
4. Your recommended approach
5. Risks or trade-offs
6. The exact files you plan to change
7. The tests or checks you plan to run

Then wait for approval.

---

## Options Requirement

When there are multiple reasonable approaches, present options.

Use this format:

```text
Option A — Minimal fix
- Smallest safe change
- Lowest risk
- May not improve structure

Option B — Cleaner improvement
- Better long-term structure
- Moderate risk
- Slightly more code change

Option C — Larger redesign
- Only suggest if genuinely useful
- Higher risk
- Requires explicit approval
```

State which option you recommend and why. Wait for the user to pick before
writing any code.

---

## After Editing Code

For every change, end with:

1. A short summary of exactly what was edited (files and intent, not a diff dump).
2. How to test or verify the change.
3. Anything that was intentionally left out and why.

If a change has not actually been run, say so explicitly — never imply a result
that was not observed.

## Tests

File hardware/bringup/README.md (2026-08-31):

# hardware/bringup/

Test procedures, measurement scripts, and recorded results for taking the rig from "assembled"
to "running the policy". **No results recorded yet as of 2026-08-06.**

[`../../docs/CURRENT_PLAN.md`](../../docs/CURRENT_PLAN.md) §7 is authoritative for sequencing.
This page is the practical checklist and the home for what comes back.

## Suggested layout

```
bringup/
├── README.md          this file — what to measure and why
├── <script>.py        measurement tooling
└── results/           dated results, one file per measurement
```

Record results **with their date and the rig state**, and keep them even when superseded — a
measurement that later turns out wrong is still the evidence for why something changed.

---

## Pre-flight, before any policy-driven run

### 1. Measure `MAX_PULL_X` and `MAX_PULL_Z` — not optional

These normalise `cmd_x_n` and `cmd_y_n`, **two of the six live policy inputs**. The current
values (6.795 / 7.361 mm) are derived from sim geometry, not from the real scope. A wrong value
does not scale the output — it hands the network an observation it was never trained on.

Pull each cable to its mechanical bend limit and record the encoder delta. **Keep X and Z
separate** — they genuinely differ, spanning 12 vs 13 joints.

### 2. Camera roll offset

In sim the tip camera is welded to the tip body and the tendon holes are in that same body
frame, so "where the lumen is in the image" and "which cable steers toward it" are locked
together — the scope can twist freely down a bend and the policy neither sees nor cares. Only a
single **fixed roll offset** between the real camera and the real cable axes can matter, and it
is unmeasured.

**The convention sim was trained under** (derived from the camera XML, *not* yet verified by the
headless `a[0] = +1` check):

| Image direction | Body axis | Cable pair | Span |
|---|---|---|---|
| right | −X | `px` / `nx` | 12 joints, 120°, `MAX_PULL_X` |
| up | −Z | `pz` / `nz` | 13 joints, 130°, `MAX_PULL_Z` |

So `a[0] > 0` steers toward image **left**, `a[1] > 0` toward image **down**. The wide image
axis (100° over 96 columns) is the X pair; the narrow axis (67.7° over 54 rows) is the Z pair.

**The measurement.** Scope in free space, pull each of the four cables in turn to a clearly
visible bend, and record which way the image content translates. Four pulls give the full
image↔cable map — offset angle and all signs — with no calibration target.

**Acting on the result:**

- **Offset is a multiple of 90°** → fix in software with a signed swap of `a[0]` / `a[1]`
  (relabelling the cables and rotating the command are the same operation here). **180° is
  free.** 90° / 270° costs the 12-vs-13-joint asymmetry — `a[0]` would then drive the 130° axis
  where it trained on 120°, ~8% in pull and ~10° in range.
- **Offset is not a multiple of 90°** → **it cannot be corrected in the action.** The obs is
  anisotropic (1.04°/column vs 1.25°/row), so a rolled real frame is not a rotation of any frame
  sim can render; the CNN is not rotation-equivariant; the bend map itself is anisotropic (a
  rotated full-scale command can exceed the elliptical reachable envelope); and the GRU state
  goes out of distribution. Fix the mount, or rotate the frame **before** the 54×96 downscale —
  which folds into the fisheye rectification LUT (§3), so it is one remap and no extra cost.

⚠️ **Trap, either route:** five of the six state slots are the action echo
(`last_action[0..2]` plus the two PD-filter slots derived from it). They must be expressed in
the **same frame as the image**. Rotating the outgoing command while feeding back the unrotated
one — or vice versa — hands the policy an image/echo pair that contradicts itself.

### 3. Fisheye rectification

The largest known observation mismatch, and perception-side only. The real lens is **122°
horizontal fisheye**; the policy was trained on **100° horizontal rectilinear**.

Run `probe_camera.py --measure_fov checkerboard` for `K`/`D`, then build a
`cv2.fisheye.initUndistortRectifyMap` LUT to a 100° rectilinear virtual camera and apply it to
the live frame before DA3. Cost is one `cv2.remap` per frame — do it on the **downscaled** frame,
not 1280×720, since the depth loop is already at 31 fps against a 25 Hz target.

### 4. Optional but informative

A **deterministic eval** and the **steering check** both change how a failed trial should be
read. The steering check matters most: deterministic mean `|a_xy|` is only **0.034**, about 3.4%
of full bend, and it is not yet established whether the policy is steering efficiently with
small precise corrections or barely steering at all and letting shaft compliance and colon
geometry do the work. The second would transfer badly. The test is to log deterministic `|a_xy|`
across full traverses and check whether it **rises at bends**.

---

## Note: the sim feeder only transports at 30 mm/s

The sim's roller feeder moves the shaft correctly at the trained 30 mm/s. With `--feed_scale 0.1`
(3 mm/s) it slips and stalls after ~9 mm — a friction-contact artefact found 2026-08-04, not
diagnosed. It matters only for slow-feed training, which is not planned: the rig is hand-fed and
the first trials judge steering at the policy's own pace, so it does not constrain them. See
[`../../docs/CURRENT_PLAN.md`](../../docs/CURRENT_PLAN.md) §8.

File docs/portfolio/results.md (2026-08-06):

> ⚠️ **Harvested 2026-08-06 from the v6_dr portfolio snapshot (`colonoscope-rl`, last touched
> 2026-06-30). NOT yet refreshed for v8_p1.** It describes the kinematic-base v6 line — no
> physical flexible shaft, no roller/capstan feeder, and the pre-v7 observation design. Anything
> here is superseded by [`../CURRENT_PLAN.md`](../CURRENT_PLAN.md) and
> [`../ITERATION_HISTORY.md`](../ITERATION_HISTORY.md), which win in any disagreement.

# Evaluation Results

## Protocol

**Checkpoint:** `v6_dr_700V3/checkpoint_p0/best_000000728_2981888_reward_1.238.pth` (~3M training steps)

**Setup:** 80 procedurally-generated colon seeds × 5 episodes per seed = 400 episodes total. All colons are exactly 700 mm long, so episode progress ∈ [0, 1] is an absolute fraction of the task — no per-seed normalisation is applied and all seeds have identical maximum reward. Deterministic policy rollout (no exploration noise). 64×64 depth observation, 32 parallel workers.

**Progress definition:** high-water-mark insertion depth as a fraction of 700 mm. An episode counts as "completed" only when the scope reaches 100% (≥ 700 mm inserted).

---

## Aggregate results

| Metric | Value |
|---|---|
| Seeds at 100% completion | 65 / 80 |
| Seeds at ≥ 80% completion rate | 74 / 80 |
| Mean progress across all seeds | 96.7% |
| Mean progress across failing seeds | 82.0% |
| Worst-seed mean progress | 59.2% (seed 61) |
| Closest near-miss (consistently) | seed 31 — 92% mean progress, only 1/5 episodes completed |
| Mean episode length | ~2,680 steps (~26.8 s at 100 Hz) |
| Primary failure mode | `stuck` — no new territory for 300 steps |

---

## Per-seed breakdown (15 worst seeds)

Seeds ranked 1–65 all achieved 100% completion on all 5 episodes. The table below shows the 15 seeds where at least one episode failed.

| Rank | Seed | Completion | Mean progress | Goal gap (mm) | Primary failure |
|---|---|---|---|---|---|
| 66 | 8 | 80% | 97.2% | 18.1 | tip_stuck |
| 67 | 66 | 80% | 96.4% | 23.0 | tip_stuck |
| 68 | 33 | 80% | 94.7% | 34.2 | tip_stuck |
| 69 | 34 | 80% | 94.0% | 38.7 | stuck |
| 70 | 6 | 80% | 91.6% | 53.9 | stuck |
| 71 | 3 | 80% | 88.7% | 72.7 | stuck |
| 72 | 40 | 80% | 85.0% | 96.3 | stuck |
| 73 | 65 | 80% | 84.1% | 102.3 | stuck |
| 74 | 7 | 80% | 83.2% | 107.7 | stuck |
| 75 | 70 | 60% | 78.3% | 139.3 | stuck + tip_stuck |
| 76 | 12 | 60% | 63.7% | 233.0 | stuck |
| 77 | 32 | 60% | 63.5% | 234.8 | stuck |
| 78 | 23 | 40% | 63.1% | 237.0 | stuck + tip_stuck |
| 79 | 61 | 40% | 59.2% | 262.0 | stuck |
| 80 | 31 | 20% | 92.0% | 51.2 | tip_stuck (×3 of 4 failures) |

*Goal gap = mean distance remaining at episode end, in mm. Completion = fraction of 5 episodes where 100% progress was reached.*

---

## Failure mode analysis

**`stuck` truncation** (no new territory for 300 consecutive steps) is the dominant failure. It typically occurs at sharp-bend sections where the scope needs to slow, steer toward the lumen centre, then re-advance — the policy succeeds at this most of the time but occasionally anchors at a haustral ring.

**`tip_stuck` truncation** (tip disk in wall contact for 50 consecutive steps) appears mostly on seeds with tight, asymmetric bends. The tip-contact obs bit gives the policy a signal to escape, but in a few episodes it cannot disengage before the truncation window expires.

**Seed 31** is the most interesting failure: mean progress 92% across 5 episodes, but only 1/5 episodes reached completion. The policy consistently navigates to the final 50 mm then gets caught in a tip-stuck cycle at what is likely a tight final flexure on that particular geometry.

---

## Limitations

- **Simulation only.** The policy has not been tested on physical hardware. Real insertion dynamics (tissue deformation, fluid, peristalsis) are not modelled.
- **Fixed colon length.** All evaluation colons are exactly 700 mm. Real colonoscopy targets vary, and the policy has no representation of remaining distance.
- **Simplified geometry.** Haustra and random bends are modelled, but the colon does not move, deform, or change lumen diameter dynamically during an episode.
- **Perception gap.** The `error_map_64.npy` noise model captures the spatial structure of DA3-SMALL's mean errors on Blender-rendered imagery. Real tissue appearance may produce different error distributions beyond what this injection covers.

---

## Training configuration

Final run: `v6_dr_700V3`, trained to 10M steps on a Linux workstation (RTX GPU). Best checkpoint saved at ~3M steps.

| Hyperparameter | Value | Notes |
|---|---|---|
| Algorithm | APPO | Asynchronous PPO via SampleFactory |
| Rollout workers | 40 × 2 envs = 80 parallel envs | |
| Rollout length | 64 steps | Also sets BPTT window for GRU |
| Batch size | 4096 | |
| Minibatches per epoch | 2 | |
| Epochs per update | 1 | |
| Learning rate | 1e-4 | Constant schedule |
| Entropy coefficient | 0.003 | Tuned to match task reward scale (~0.001/step) |
| Gamma | 0.99 | |
| GAE lambda | 0.95 | |
| PPO clip ratio | 0.2 | |
| Max grad norm | 0.5 | |
| Optimizer | Adam | β1=0.9, β2=0.999, ε=1e-6 |
| GRU hidden size | 512 | 1 layer |
| Encoder | NatureCNN → 512D MLP | Custom depth CNN (`sf_encoder.py`) |
| Normalise returns | True | |
| Normalise observations | False | Depth normalised per-frame in env |

---

## Full data

`docs/eval_results.csv` contains the complete per-seed table with all columns: completion metrics, progress mean/min/max, goal gap, reward, steps, contact force, weld lag, and per-reason termination counts.

View training curves:
```bash
tensorboard --logdir docs/training_curves/
```

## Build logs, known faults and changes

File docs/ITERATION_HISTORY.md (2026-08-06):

# Iteration History — Autonomous Colonoscope Navigation (v1 → v7_shaft)

Consolidated design history of the Mujuco_V2 project (May–July 2026), written as the
single source for GitHub/portfolio write-ups. Every version's architecture, reward
design, modelling assumptions, results, and reason for supersession is captured here so
the old code and checkpoints can be archived.

**Attribution:** the 25-hinge tendon-driven videoscope tip simulation (`simulation/`) and
the photorealistic Blender colon-rendering environment were **supervisor-provided**.
The author's own work: the Stage-1 procedural MuJoCo colon (`Colon_mesh_xml.py`), the
perception CNNs, the closed-loop v1 controller, the DA3 fine-tune, and all collision and
RL work (collision meshing, environment, reward engineering, cheat diagnosis, domain
randomisation, the flexible shaft and V-groove roller design). One nuance worth stating
precisely in any write-up: `colon_generator.py`, used by every RL version from v2 onward,
is a pure-NumPy **port of the supervisor's Blender colon generator** — the procedural
distribution is the supervisor's; the port, the collision meshing, and all later
modifications are the author's.

**Naming convention warning:** there are two overlapping numbering tracks. *Codebase
generations* are folders (v1, v2_collision, v3_sample_factory, v4_hierarchical,
v5_smooth, v6_dr, v7_shaft). *Training runs* are numbered within a generation
(ppo_v1…ppo_v8 inside v2_collision; v9_sf…v17_sf inside v3_sample_factory;
v7_shaft_v1…v4 inside v7_shaft). Sections below are organised by codebase generation,
in chronological order of work (note v2_collision's run series ppo_v7/ppo_v8 predates
the v3_sample_factory folder).

---

## 0. Timeline

| Generation | Dates (2026) | Framework | Key idea | Result | Why superseded |
|---|---|---|---|---|---|
| Stages 1–3 | ≤05-25 | MuJoCo + PyTorch | Procedural colon, steering CNNs, scope tip | Working components | Foundations, not superseded |
| v1 | 05-25→26 | Proportional control | CNN target pixel → tendon commands, no collisions | Full traversal, no crash | No physical contact — controller never coped with constraint |
| DA3 depth | 05-27→28 | Depth Anything 3 | Full metric depth from RGB (head-only fine-tune) | 2.4–3.3 mm MAE, metric, 20 FPS | Not superseded — became the RL noise model |
| v2_collision | 05-28→06-24 | SB3 PPO | Physical scope–wall collisions + RL steering | 66%/85% runs both **cheated** | Sync-barrier throughput + honest reward needed APPO rework |
| v3_sample_factory | 06-24→25 | SF APPO | Async training, exploit whack-a-mole (v9–v17) | v17: mean 52%, max 100% | Jittery raw-joint control; exploit fixes matured |
| v4_hierarchical | 06-26 | SF APPO | RL picks image target, PID steers | **Abandoned** — provably ≡ v3 | Centroid dilemma (see §7) |
| v5_smooth | 06-26→29 | SF APPO | PD-smoothed tendon control, clean rebuild | 44% completion, 89.7% mean progress | Ideal-condition sim; no sim-to-real story |
| v6_dr | 06-28→29 | SF APPO | Domain randomisation + real CNN-error noise | **93.75% completion, 96.7% mean progress** (80 seeds) | Kinematic base advance was the last big sim shortcut |
| v7_shaft | 07-01→02 (+07-08→10) | SF APPO | Physical flexible shaft + roller feeder | **~92% mean progress, ~90% completion** (v2); v4 35.0%/72.3% pre-fix | Superseded by v8_p1 — v4 trained+evaluated 07-10 on a generator later found self-intersecting (fixed same day) |
| v8_p1 | 07-11→13 | SF APPO | V8 Layer 1: cable-extension obs (no force signal); tendon integral control; shaft/tip compliance rework | **63.2% mean progress, 25.7% completion** (v8_p1_v1, post-fix half) | **LIVE line.** `stuck` failure eliminated; `tip_stuck` then 73.3% of episodes — diagnosed 07-13 as a truncation-window artefact, fix untrained |

---

## 1. Foundations (Stages 1–3)

**Stage 1 — procedural colon (author's).** A seeded script generates a 500 mm
anatomical centreline (ascending → hepatic flexure → transverse → splenic flexure →
descending), ~15 mm internal radius, 35 haustral folds (single soft-arc folds with
random angular centres, 60° edge fade), a slight 3-lobed taenia-coli cross-section,
per-vertex normals for smooth shading, and endoscope-style tip lighting as the only
illumination. Outputs mesh + ground-truth centreline + MuJoCo scene. Key rendering
lessons: shadow acne from the tip light required `castshadow="false"`; depth-buffer
znear/zfar needed tightening; the passive viewer and offscreen renderer *share lighting
state* (toggling the viewer headlight corrupts what the CNN sees).

**Stage 2 — steering CNNs (author's).** ResNet-18 regressors predicting a "where to
drive next" pixel from RGB. Label strategies compared on identical frames:
- *deepest-depth-blob centroid* — shaky at corners (deepest region occluded behind bends);
- *deepest-visible-centreline point* — over-rotates at flexures (label sits on the wall
  corner where the centreline disappears);
- *pure-pursuit look-ahead* at 30/15/10 mm — 30 mm collapses to the wall corner at every
  bend (fallback fires), 15 mm traversed end-to-end but clipped walls at both flexures,
  **10 mm gave the gentlest corner commands and became the keeper**.

**Stage 3 — videoscope tip (supervisor-provided).** One articulating section: 26 disks
chained by 25 alternating-axis hinges, 4 antagonistic tendons, 9 mm OD. The author's
contribution is integration, not the scope model itself.

## 2. v1 — CNN closed-loop controller (no collisions)

First coupling of perception and actuation. Per step: render tip camera → CNN target
pixel → deadzone → rate-limited proportional update of the two antagonistic tendon
pairs → advance the base kinematically along the ground-truth centreline. With the
10 mm look-ahead CNN the scope traverses the full colon with no visible tip-cam crash.

**Modelling assumption that defined the next generation:** the colon mesh had
`contype=0` — *no scope–wall collisions*. The controller never had to cope with
physical constraint, and the base advance was a perfect kinematic rail.

**Follow-up (dropped):** swapping the steering CNN for the fine-tuned depth model with
a depth-centroid aim point + PD control, still collision-free, could *see* the lumen
reliably but could not traverse — it oscillated between good views and wall jams, and
every gain change traded one failure mode for another. Conclusion (2026-05-28): "target
pixel only, no collisions, basic controller logic is not cutting it." This motivated
both collisions and RL.

## 3. Depth perception — DA3 fine-tune (feeds every later version)

Depth-Anything-3-SMALL was evaluated as a full-depth-field alternative to the single
target pixel. Zero-shot it output only *relative inverse* depth (median GT/pred ratio
0.029, ~7 mm scale-aligned MAE) and failed structurally at flexures — placing the
"deep" region on a brightly lit wall instead of the off-centre lumen hole, the exact
frame type steering needs most. A **head-only fine-tune** (11% of parameters, 1469
Blender renders from the supervisor's photorealistic environment, mixed
scale-invariant-log + L1-metric loss) fixed all of it:

| Metric | Zero-shot | Fine-tuned |
|---|---|---|
| Held-out geometry MAE | 9.49 mm | **3.28 mm** |
| Unseen pilot set MAE | 7.10 mm | **2.40 mm** |
| Output type | relative (ratio 0.029) | **metric (ratio 1.014)** |
| Flexure failure | present | **fixed** |
| Speed | ~20 FPS | ~20 FPS |

A second fine-tune round (RD_V2: 320×180, 100° FOV, 1500 frames) reached **1.60 mm val
MAE** (8.30 mm baseline). Its per-pixel error statistics became v6's observation-noise
model (§9). Pipeline lives in `perception/rd_v2/`.

## 4. v2_collision — SB3 PPO with physical collisions (runs ppo_v1…ppo_v6)

**Collision modelling assumption:** MuJoCo's default mesh collision convex-hulls the
mesh — for a hollow tube that's a solid blob the scope ignores. Fix: **per-triangle
thin-prism decomposition** — every wall triangle becomes a 6-vertex convex mesh extruded
along its normal; adjacent prisms share edges so the wall behaves like the smooth mesh
(~5k prisms, ~1500 physics steps/s).

**RL formulation:** action `Box(-1,1,(3,))` = two tendon-pair commands + base-advance
rate; obs = 64×64 metric depth + small state vector; base attached to a kinematically
driven target via a **1-DOF slide joint** (not a free joint) so a jammed tip lags
instead of being forced through; reward = high-water-marked progress + goal − collision
penalty + waypoint credit.

**Run history — the two cheats are the key finding:**

| Run | Config change | Outcome |
|---|---|---|
| ppo_v1–v2 | collision penalty 2–1×10⁻⁴ | ~0% — any motion net-negative, agent froze |
| **ppo_v3** | penalty 2×10⁻⁵, ent 0.01 | **66% — CHEAT 1:** free-floating 6-DOF base let it drag itself backward and flip orientation |
| ppo_v4 | 1-DOF slide + dynamic slide floor + 0.5 mm walls (cheat closed) | flat 0.5% — reward became too sparse |
| ppo_v5 | + waypoints, ent 0.03 | flat 1% — entropy term ~100× the task signal |
| **ppo_v6** | ent 0.015 | **85% — CHEAT 2:** used the chain's ~770° of total bend to curl into a ball and punch *through* the 0.5 mm prism walls at bends |

Both high scores were illusory — the agent solved the *simulation*, not the *task*.
Supporting lesson: `ent_coef` must be calibrated to the task-reward magnitude
(~0.001/step here), not copied from defaults.

## 5. Lumen-gate rewards (runs ppo_v7/v7b/v7c) and THE REFRAME

Instead of stiffening the scope to stop cheat 2, three variants of a "forward-look
gated reward" were tried: progress credit gated by `aim = open_factor × fwd_factor`
(central depth openness × alignment with the centreline tangent). All three failed to
learn (v7: gate threshold too deep, reward trickle; v7b: entropy-dominated; v7c:
entropy fixed but exploration/credit-assignment still flat at ~0%).

**The reframe (user-driven, 2026-05-29) — the project's core design principle since:**
1. **Aim-shaping defeats the purpose of RL.** Rewarding "point at the lumen" bakes the
   perception→aim mapping into the reward — re-implementing the analytic aim point
   already available without RL. Steering must *emerge* from the depth observation.
2. **Cheat prevention belongs in physics/termination, not reward shape.** The slide
   architecture already stalls a mis-aimed tip; the only hole was wall *penetration*.
3. Reward stripped to pure outcome: high-water-marked progress (+ later, force terms).

## 6. Force-based termination session (run ppo_v8, SB3)

Closed cheat 2 with physics-side measurement instead of reward shaping. Three candidate
"insertion force" signals were calibrated under a scripted max-curl replay:
`qfrc_constraint` on the slide DOF (7× curl/gentle ratio — misses the cheat because the
curled chain moves *ahead* of the target so the slide floor never engages),
`cfrc_ext` on the anchor (zero — contacts land on disk bodies), and **sum of
`mj_contactForce` magnitudes (1242× ratio — chosen)**. `MAX_INSERTION_FORCE = 30 N`;
`force_norm` entered the observation vector and `force_norm ≥ 1` terminated the
episode. Max-curl now terminates in 8 steps; gentle advance reads ~0.006. SB3 run
ppo_v8 reached only mean 2.9–3.1% but **the curl cheat was dead** — and SB3's sync
barrier (30–60% core utilisation) had become the bottleneck, motivating the APPO port.

## 7. v3_sample_factory — APPO port and the exploit ladder (runs v9_sf…v17_sf)

Sample Factory APPO replaced SB3: env workers, policy worker, and learner run
asynchronously with no sync barrier (~1500–2000 fps vs ~450). The env stayed in
v2_collision; only the training harness changed.

**Exploit/fix ladder (each run's failure was diagnostic):**

| Run | Reward/termination | Result | Root cause |
|---|---|---|---|
| v9 | new-territory + 30 N hard termination | collapsed, force:100% | **sprint-and-die**: terminal at force limit lets a sprinting policy end episodes cheaply |
| v11 | W_FORCE=0.01 per-step | stagnant 2.6% | penalty 33× progress signal, advantage ≈ 0 |
| v12 | W_FORCE=0 | plateau 20% | sprint to first bend, terminate |
| v13 | terminal force penalty | KL=171970, NaN | 250× scale mismatch blew up log_std |
| v14 | per-step lumen reward | 3.4% | **lumen farming** — sit still and collect |
| v15 | lumen multiplier + hard force gate `×(1−f)` | 20%→9% | gate makes "do nothing" the optimum |
| v16 | gate removed | OOM crash ~15–18% | EGL mmap leak; force-limit exploit back at 99% |
| **v17** | see below | **mean 52.3%, max 100%** | — |

**v17's winning combination:** tip_contact obs bit (defeats the "UFO posture" — tip
pressed sideways into a haustra ring where the camera sees only wall);
high-water-mark stuck metric (`d_max_s`, not raw per-step delta — farming-proof);
stuck/tip_stuck as *truncation not termination* (bootstrapped value ≠ 0, so reaching an
obstacle isn't punished); ROLLOUT=64 so the BPTT window covers a full ring approach;
ENTROPY=0.003; obs slimmed 37→10-D (dropped 25 hinge angles — colon geometry the depth
image already covers); stiff wall contacts (`solref="0.002 1"`, 3 mm walls) to stop
tunnelling; renderer recycled every 50 episodes (EGL mmap leak); W_TIP_PENALTY=0.001 +
TIP_STUCK_WINDOW=50 added **only after** mean >30% (from step 1 they are a bootstrap
trap — random policies never see positive reward).

**Post-training eval bug (cost a day):** SF stores the GRU hidden state under
`"new_rnn_states"`, not `"rnn_states"` — eval/viewer code that `.get("rnn_states",…)`
silently zeroed the GRU every step, scoring 2–3% instead of 52%.

**Verdict:** navigation learned, but control was jittery — RL directly commanding raw
joint bend targets with exploration noise produced oscillating micro-corrections.

## 8. v4_hierarchical — the dead end (abandoned, no training kept)

Idea: RL picks a *point in the image* to aim at; a low-level PID drives the tendons to
centre it — hoping to smooth v17's jitter. Abandoned on analysis:

**The centroid dilemma.** For the hierarchy to differ from direct control, someone must
close the loop between the chosen image point and the tendon commands:
- put centroid feedback *in the controller* → the controller steers, RL learns nothing;
- put the centroid *in the observation* → not IRL-valid (needs an image-processing
  pipeline unavailable on the real device — a standing project constraint);
- neither → `target_x → cmd_x` is just a scaled linear map, **functionally identical to
  v3's direct tendon control**.

Also independently broken: v17's late-training anti-exploit penalties were applied from
step 1 (bootstrap trap), a PID integral wind-up bug, and a deadzone tested on the wrong
signal. Lessons kept; folder never trained to completion.

## 9. v5_smooth — clean rebuild with PD-smoothed control

Self-contained rebuild (the "version bundle" pattern every later generation follows):
each folder carries its own copies of all dependencies. Control smoothing moved into
the *env*, IRL-validly: a **PD position controller (KP=0.06, KD=0.30)** turns the
policy's tendon setpoints into rate-limited commands — the RL output is smoothed the
way a real motor controller would, not by post-hoc filtering. Advance slowed to
0.3 mm/step. Depth 48×48, frame-relative normalisation (`depth/depth.max()` — keeps
contrast when pressed against a wall, where a fixed metric clip goes near-black).
10-D state: cmd_x/y, progress placeholder (always 0 — true progress is privileged sim
information), force_norm, net_fx/fz (motor-current analogues), last_action, tip_contact.
Reward: `W_PROGRESS × new_territory × (0.3 + 0.7×(1−force_norm)) + W_GOAL − W_TIP_PENALTY`.
Colon generator rebuilt as piecewise circular arcs (1–3 bends, R=40–90 mm) with a
curvature-safety margin.

**Result (5M steps, 40 workers × 2 envs): 44% full completion, 89.7% mean progress,
max 100%.** Residual failures: tip-contact truncations at sharp bends where ±90°
deflection is insufficient.

## 10. v6_dr — domain randomisation MILESTONE

v5 assumed ideal conditions: perfect depth, exact actuator response, under-spec
deflection. v6 (folder `navigation/v6_dr/`, frozen) closed the sim-to-real gaps
*without hardware calibration* — an explicit design decision after rejecting an IK
model (tendon gain is not static: it changes with shaft bend friction, so free-air
calibration is stale the moment the scope curves).

1. **Deflection ±90°→±120°/axis** (real endoscope range).
2. **Per-episode domain randomisation, never observed by the policy:** tendon gains
   45–100% per axis, dead zones 0–3%, command lag 0–2 steps, advance gain 65–100%. The
   policy must infer the episode's regime from visual feedback — the same feedback a
   human operator has.
3. **Depth 48→64 px.**
4. **Real perception noise:** the RD_V2 DA3 model's per-pixel relative-error map
   (`error_map_64.npy`, from 500 held-out frames) injects multiplicative noise
   `depth += N(0, error_map) × depth` — the policy trains under the deployed depth
   network's actual uncertainty profile.
5. **Fixed 700 mm colon** (uniform reward scale across seeds), harder bends (2–4 bends,
   up to 150°).
6. **Goal bonus removed** (no IRL endpoint; it incentivised rushing) + small terminal
   stuck penalty (−0.05).

**Result (run v6_dr_700V3, best checkpoint at ~3M steps, eval 80 seeds × 5 episodes):
93.75% completion rate, 96.7% mean progress, 65/80 seeds at 100%.** Eval CSV:
`navigation/v6_dr/runs_sf/v6_dr_700V3/eval_best_…_eps5_seeds80_….csv`.

## 11. v7_shaft — physical flexible shaft + roller feeder (superseded by v8_p1)

v6's last major shortcut: the base advanced on an infinitely strong kinematic rail. In
reality a ~1.6 m flexible shaft transmits push force from outside the body, wall
contact at bends carries the force around corners, and slip/buckling/looping are the
clinically dominant failure modes. v7_shaft replaces the rail with real mechanics:

**Architecture.** 30× two-DOF universal joints (X-hinge + Z-hinge pairs, no torsional
DOF — matching a real colonoscope), even pairs fused into single 20 mm capsules to
halve contact count (+52% fps). `shaft_link_0` is on a **free joint** — the shaft is
held only by roller grip and wall contact. An **entrance roller/capstan feeder** (2
rings × 4 position-controlled rollers; two rings because one constrains lateral
position but not rotation) feeds the shaft in. Action a[2] drives roller target angle;
**the roller can genuinely slip**, so progress is measured from the shaft's true
physical position, never the commanded angle. Episode termination redesigned:
`shaft_exhausted` fires when the physical shaft end reaches the rollers — a natural
physical boundary replacing the arbitrary distance goal (a slip-heavy episode can
exhaust the shaft with low progress and earns accordingly).

**The roller-slip saga (the hard engineering of this generation):**
- Post-release creep: fixed by preload 0.4→0.6 mm (friction coefficient increases made
  it monotonically *worse* — high friction on a curved-on-curved contact produces
  stick-slip chatter, not grip).
- Slip under real driving load (v7_shaft_v1 plateaued at the first bend, 24.7% mean):
  root cause was geometric — a plain cylinder crossing the shaft at 90° is a *point*
  contact no matter the preload. **Fix: V-groove rollers** — two mirrored frustum mesh
  geoms per roller flaring *outward* from the waist to cradle the shaft. Must be two
  separate meshes: MuJoCo convex-hulls each mesh geom, and a single waist-and-shoulders
  mesh silently hulls back into a cylinder. Groove flare helps monotonically
  (contact-area lever); preload does *not* scale grip once contact is established
  (solref already near-rigid).
- Shaft stiffness walked 2.0→0.25 alongside (Euler-buckling check: short-span kinks
  stay force-limited at 0.25).

**The MuJoCo friction/priority lesson (transferable):** MuJoCo combines contact
friction by element-wise *max* — verified by reading `d.contact[i].friction` directly
(inferring it from slide distance gives wrong answers; the soft solver creeps below the
nominal static threshold). The shaft's low lubricated friction never took effect
against the wall's higher default. Using `priority` to force it through **broke
training**: priority hands over the *entire* contact parameter set, silently replacing
the wall's tunnelling-prevention `solref` with the soft default. Clean fix: lower the
scene's shared default friction instead; never use `priority` without also setting
explicit `solref/solimp` on the winning geom.

**Reward-scale pathology and fix:** v7_shaft_v1's reward *improved* while progress
*declined* — the policy learned to trigger `stuck` truncation early because the
unbounded per-step tip penalty could outgrow the distance-capped progress budget.
Diagnosed by comparing consecutive log windows (reward-up-while-progress-down is the
tell). Fix: `W_PROGRESS` 2.0→4.0, fresh network (**v7_shaft_v2**).

**Result (v7_shaft_v2, 8M steps, ~4.8 h on the Linux rig): ~92% mean progress, ~90%
completion (`shaft_exhausted`).** Best checkpoint at
`navigation/v7_shaft/runs_sf/v7_shaft_v2/checkpoint_p0/best_000001700_6963200_reward_0.581.pth`.

**Post-v2 hardening (July 8–10):** colon generator hardened (bend radii 32–48 mm near
the shaft's ~29 mm mechanical minimum; finer spline sampling; entrance-straight
invariant enforced so the pre-threaded shaft spawns inside the lumen); a
`<size memory="32M">` arena fix for high-contact scenes (generic MuJoCo bug, keep
everywhere); WSL2 investigated and **rejected** for training (GPU paravirtualization is
structurally bad for per-step small-render workloads; CUDA-IPC fixes
`ptrace_scope=0` + `expandable_segments` are known-good if ever needed); training
returned to the native Linux rig. Feasibility lesson: the generator rejection-samples
segment lengths against the total budget, so straight-length ranges must scale with task
length or generation goes infeasible (500 mm + 6–7 bends is a hard geometric wall —
0/100 seeds).

**v7_shaft_v3 (the WSL2 attempt, 07-08→10).** Resumed from v2's best checkpoint and run
under WSL2 to 8.33M steps. It never beat v2's `reward_0.581` — the run is the evidence
behind the WSL2 rejection above, not a result in its own right. Checkpoints discarded;
`config.json` + `sf_log.txt` archived at `docs/run_archive/v7_shaft/v7_shaft_v3/`.

**v7_shaft_v4 (trained 2026-07-10).** Same physics as v2, retargeted at a 500 mm / 4–5
bend colon (density-matched to the 700 mm / 5–7 task, 100/100 seeds validated), 50-link
shaft, `EXPERIMENT="v7_shaft_v4"`. Ran the full 10M-step budget on the native Linux rig
(`andrew-HP-Z640-Workstation`), finishing at 10,010,624 steps. Best policy
`best_000002330_9543680_reward_0.231.pth` — training reward was **still climbing at the
end** (0.209 → 0.231 over the final ~40 min), so the budget, not convergence, stopped
it. v4 is *not* comparable to v2's 0.581 (different colon, so different reward scale).

**v7_shaft_v4 eval (2026-07-10, WSL2/osmesa CPU, 24 workers, 80 seeds × 3 episodes =
240 episodes): 35.0% completion, 72.3% mean progress.** Distribution was sharply
bimodal, not a uniform shortfall: 12/80 seeds went 3-for-3 (100% every episode), 36/80
went 0-for-3, only 32/80 mixed. Failing episodes were almost universally `tip_stuck`
(camera pressed sideways into a haustral ring, blind — the "UFO posture" from §13) —
not force limits, not `max_steps`. This eval used CPU rendering (osmesa) rather than
the GPU EGL path used for v2's numbers; a same-seed, zero-action parity check found the
two rasterizers agree to ~0.1–0.3% on identical geometry (well inside the ~1.6 mm DA3
sensor noise the policy already trains under), so the renderer is not the source of the
result. **This eval also predates the self-intersection fix below — see that entry
before treating 35%/72.3% as a clean read of the policy.**

**Colon-generator self-intersection bug (found and fixed 2026-07-10).** Two of the 80
eval seeds (43, 34) produced near-zero-progress episodes for a reason that had nothing
to do with the policy: seed 43 ejected the shaft in 18 steps with mean contact count
~10× a healthy step; seed 34 showed the same signature, milder. Root cause: each colon
chains 4–5 bends of 80–150° about independently random 3D axes — 320–750° of total
turning, more than a full loop — and `generate_colon`'s only geometric guard
(`centreline_min_curvature_radius`) checks *local* curvature within a single bend. There
was no check for two *distant* sections of the same centreline swinging back through
each other in 3D. A scan of all 80 eval seeds found the walls actually interpenetrate
(closest-approach ratio to `2×tube_radius` below 1.0) on **6/80** — seeds 43 and 34 both
fold back within the first ~15% of arc length, plugging the lumen right past the
entrance and making the episode unsurvivable regardless of policy skill; the other 4
were milder and didn't always prevent completion. The remaining 74/80 already cleared a
comfortable margin (~1.2–1.5×), so this was a tail bug, not a systemic one — removing
just the 2 worst seeds only lifts the 35.0% figure to ~35.9%, so it is **not** the
primary explanation for v4's shortfall against v2 (still-climbing reward + a harder,
denser-bend task are the leading candidates for that).

Fix in `colon_generator.py`: `centreline_min_self_distance()` measures closest approach
between centreline points more than 6 cm apart in arc length (far enough to exclude
same-bend/local-thickness comparisons), folded into `generate_colon`'s existing
rejection-retry scoring alongside the curvature and length checks
(`SELF_INTERSECT_MARGIN = 1.02` — the literal "walls must not touch" boundary, plus
tiny fp slack; population already clears far higher margins naturally, so this rejects
only genuinely self-intersecting layouts). Also added a cheap directional bias in
`random_ctrl_points`: at each bend, of the two available arc directions, prefer the one
curving away from the path already travelled — doesn't guarantee avoidance (that's what
the rejection check is for) but reduces how often it needs to fire. Re-scanning all 80
seeds post-fix: **0/80 self-intersecting** (down from 6/80). v4's checkpoint and the
35.0%/72.3% eval above both predate this fix and reflect the old geometry distribution.

**The v4-retrain thread was never run** — it was overtaken by v8_p1 (§12), which forked from
v7_shaft carrying the corrected generator. v7_shaft is therefore superseded, and v4 vs v2 was
never settled. Its one durable finding is the bimodal seed split (12/80 seeds 3-for-3, 36/80
0-for-3, failures almost all `tip_stuck`), which §12 retro-explains: sharp bends were
*unsolvable* under the 50-step tip-contact truncation, at any skill level. That was an
environment bug, not a v4 policy deficiency.

## 12. v8_p1 — V8 Phase 1: hardware-matching observation (LIVE line)

Folder `navigation/v8_p1/`. Implements **Layer 1 only** of the original V8 plan — the
observation-vector swap. Layers 2 (anatomical colon) and 3 (gravity) are *not* in it; they
became "Phase 2", still unstarted. Note the folder is `v8_p1/`, not the `v8/` path the old
plan used throughout (that folder never existed). The original plan is archived at
[archive/superseded_plans/V8_PLAN.md](archive/superseded_plans/V8_PLAN.md) — historical only,
never take paths or numbers from it.

**The observation change (the point of the generation).** `force_norm` — the summed
contact-force magnitude — was dropped from the observation. It has no real-hardware sensor
equivalent: nothing on the physical device measures total scope-wall contact force. It was
replaced by **net per-axis cable extension**, computed from MuJoCo's free `data.ten_length`
output as `(ten_length[nx] - ten_length[px])` and `(ten_length[nz] - ten_length[pz])`,
normalised by `2 × max_pull`. That maps directly onto a linear encoder on each antagonistic
cable pair — a sensor the real robot actually has. `net_fx`/`net_fz` (motor-current
analogues) were dropped in the same pass, so the state vector went **9-D → 8-D**:
`[cmd_x, cmd_y, ten_x, ten_z, last_action×3, tip_contact]`. `force_norm` itself is untouched
in the reward path and the info dict — only its presence in the *observation* changed.

**The governing principle (worth stating in any write-up):** only give the policy signals the
simulation can model with genuine fidelity — kinematic, encoder, and contact-boolean signals.
Never feed it force- or friction-derived signals. Sim friction is not real friction, so the
policy either overfits a fantasy signal or learns to ignore it as noise. Cable *extension* is
a kinematic quantity; cable *tension* is not, and was deliberately not used.

**Reward rebalance (07-11).** Two changes, both undoing earlier over-correction:
- `W_FORCE_MULT` 0.7 → **0**. The force discount on progress reward assumed shaft-wall contact
  was pathological. It isn't — the shaft *physically cannot clear a colon bend* without
  pressing against the inside wall, and light grazing alone reads `force_norm ≈ 0.2`, taxing
  ~14% off every metre of legitimate progress. This was likely reproducing a milder version of
  the v11/v12 "policy refuses to move" collapse.
- `W_PROGRESS` 8.0 → **4.0**. The 8.0 doubling had been calibrated *while* the force discount
  was still taxing progress; zeroing the discount restores much of what the doubling existed to
  compensate for, and stacking both risked overshooting the other way.

**Colon-generator diversity fix (07-11).** The anti-loop directional bias added alongside the
07-10 self-intersection fix (§11) was removed — it was suppressing genuine layout diversity.
Re-verified: diversity up, self-intersection still 0/80. The rejection-sampling
`centreline_min_self_distance()` check remains and is what actually guarantees non-intersection;
the bias was only ever an optimisation to make it fire less often.

**The steady-state droop problem and the tendon integral fix (07-12).** The tip's P+D tendon
actuators (`ACTUATOR_KP = 6000`, `ACTUATOR_DAMPING = 0.08`) leave a steady-state droop against
the tip joints' own restoring stiffness — the commanded bend is never fully reached, and under
sustained command the tip settles into a persistent S-shape drift. The naive fix (cap or remove
the joint stiffness) was rejected as it re-opens the bend-range problem. **Real fix: a true
integral term.** MuJoCo's affine bias law has no accumulator, so a PID cannot be expressed in one
actuator — the integral was added as a **separate `dyntype="integrator"` actuator per tendon**,
whose force sums with the original P+D actuator at the same tendon (`ACTUATOR_KI = 36000`, ~6×
`ACTUATOR_KP`, chosen empirically to converge in ~1–2 s, well inside a ~6–7.5 s episode, without
overshoot). Anti-windup included. The integral actuator's `gainprm` gets the **same
domain-randomisation gain rescaling** as the P+D actuator — otherwise the policy could simply
lean on the un-randomised integral term and DR gain would stop meaning anything.

**The shaft-vs-tip compliance inversion (07-12).** Live-viewer inspection of the 37%-plateau
checkpoint showed the shaft not buckling *at all* at tight bends while the much more compliant
tip visibly over-deformed — backwards from a real endoscope, where the shaft is the part that
yields. Fixes, all applied together: `SHAFT_STIFFNESS` 0.25 → **0.05**; the shaft/tip junction
stub shrunk from a full 10 mm shaft unit to **2.5 mm** (matching the tip's own disk spacing — it
had been acting as a stiff moment arm dumping bend load straight onto the tip); tip joint
stiffness reinstated at **0.5**; and shaft joint density raised **50 → 76 links** (25 → 38
universal-joint pairs) to let the shaft form a smoother bend curve instead of concentrating load
at sparse joints.

**Training run v8_p1_v1 (2026-07-12 → 07-13, native Linux rig, 40 workers).** One experiment
directory, but **two distinct physics regimes** — the learner was stopped at 10.01M steps, the
fixes above were applied, and training **resumed from the 10M checkpoint** (weights carried over,
step counter continued) for a further 5M. The two halves are therefore not one run and must not
be read as a single curve:

| | steps 0 → 10.01M (pre-fix) | steps 10.01M → 15.02M (post-fix) |
|---|---|---|
| mean progress | **37.4%** (flat from ~3M) | **63.2%** |
| completion (`shaft_exhausted`) | ~0% | **25.7%** |
| `stuck` truncation | **82.2%** | **0.0%** |
| `tip_stuck` truncation | 17.8% | **73.3%** |
| best reward | 0.440 | **0.920** (at 13.9M) |

**Reading of that table — the fix worked, and it unmasked the next constraint.** The integral
control plus the compliance changes **completely eliminated the `stuck` failure** (82% → 0%): the
shaft now advances reliably. What was left standing was the tip jamming into the wall. In the
final 1M steps, `stuck`, `ejected` and `max_steps` truncations are all **exactly 0%** — every
single non-completing episode ends in `tip_stuck`. One failure mode, cleanly isolated. (Caveat
for anyone quoting the 60%: the post-fix policy is a *warm start* from 10M steps of a different
physics regime, and it only saw 5M steps of the current one. Reward peaked at 13.9M and drifted
slightly down to 15M — plateau-ish, but not conclusively converged.)

**`tip_stuck` diagnosed (07-13) — the bend was not hard, it was impossible.** `TIP_STUCK_WINDOW`
truncated the episode after 50 *consecutive* steps of tip-disk-to-wall contact, with **no check
on whether the scope was still advancing**. At `ADVANCE_RATE_MAX = 0.3 mm/step` that caps
in-contact travel at **15 mm** — far shorter than the in-contact arc of a 32–48 mm-radius bend. So
at a sharp bend the policy had *no surviving strategy*: push through and it truncates mid-bend,
hold still and it truncates anyway. The manoeuvre was simply absent from the MDP, at any skill
level. This also retro-explains the sharply bimodal seed distribution in the v7_shaft_v4 eval
(§11: 12/80 seeds 3-for-3, 36/80 seeds 0-for-3) — gentle bends clear inside 50 contact-steps,
sharp ones cannot, and no amount of training changes that. **`tip_stuck` was firing on a proxy
(tip touching wall) that is not equivalent to the thing it was meant to catch (tip not
progressing).** The genuine UFO posture is caught independently by `stuck` (300 steps / 2 mm of
new territory), and progress is measured at `disk_0` — the shaft/tip junction — so a jammed tip
*cannot* farm reward by buckling shaft in behind it. `tip_stuck` was never the load-bearing
anti-UFO guard it was assumed to be.

**A second, softer blocker found in the same pass (not yet fixed).** With `W_FORCE_MULT = 0` and
`W_SHAPING = 0`, per-step progress reward at full advance on new territory is
`W_PROGRESS × ADVANCE_RATE_MAX = 4.0 × 0.0003 = +0.0012`. `W_TIP_PENALTY` is `−0.001/step`
whenever the tip touches the wall. So advancing at *full speed* while in wall contact nets only
**+0.0002/step**, and any bend-clearing slower than **0.25 mm/step (83% of max)** is
**net-negative reward**. Since clearing a bend requires wall contact and is necessarily slower
than a straight sprint, the reward gradient actively discourages the one manoeuvre the policy
needs. This is the same argument that retired `W_FORCE_MULT`, applied to the tip. It was left in
place deliberately (user's call: the easier colons remain learnable under it, so it still teaches
the tip not to park on the wall) — but if the window increase alone doesn't lift progress, **the
fix is to gate the penalty on non-advancement** (`r_tip = −W_TIP_PENALTY if _tip_in_contact and
ds_actual <= 0`), *not* to re-raise `W_PROGRESS`, which has already failed twice.

**Changes applied 2026-07-13 (all three untrained as of writing; `v8_p1_v2` is the retrain).**

**(1) `TIP_STUCK_WINDOW` 50 → 150.** Buys ~45 mm of in-contact travel — enough for a typical bend
arc — while staying 2× tighter than `STUCK_WINDOW`. `W_TIP_PENALTY` deliberately unchanged (see
above: the easier colons remain learnable under it, so it still teaches the tip not to park on the
wall).

**(2) Shaft joint density reverted 76 → 50 links.** Two reasons pointing the same way: the 76-link
shaft **buckled hard at the entrance** (too flexible in practice), and the 1.5× joint count cost
~40% of rig throughput. Benchmarked on Windows, seed 0: **1.58× faster physics** (592 → 938
mj_step/s), mean contacts 60 → 52, `<body>` nesting depth 103 → 77.
This was a **literal** revert — `SHAFT_STIFFNESS`/`SHAFT_DAMPING` were *not* density-compensated
back, which is the point: effective beam stiffness and damping both scale as
`per-joint value × segment length`, so restoring the 20 mm fused-pair segment raises both by
**1.52×**, which is exactly the anti-buckling stiffening wanted. Two silent side effects of the
original density bump are also undone: shaft mass 396 g → 259 g (`SHAFT_LINK_MASS` had never been
density-compensated) and effective damping returns to its long-validated value.
**Consequence: joint density's individual contribution to the 37% → 60% jump was never isolated**
— it went in as one of five simultaneous changes. The revert is also the experiment that measures
it.

**(3) Shaft SHORTENED 50 → 44 links — the scope was longer than the colon.** Spotted in the
viewer: the tip was leaving the colon entirely. The arithmetic confirms it. A 50-link shaft builds
to **492.5 mm** (10 mm `link_0` + 24 fused 20 mm pairs + a 2.5 mm end stub); plus the 62.5 mm
flexible tip that is **555 mm of scope in a 500 mm colon**. `shaft_exhausted` fires when the
shaft's *base* reaches the roller ring (20 mm outside the entrance), so the episode ran until the
**tip was at ~535 mm — about 35 mm out the far end of the colon**, in free space with no wall
contact, for the last ~117 steps. And because `new_territory` reward is **not capped at `s_goal`**,
the policy was being *paid* to drive the tip out of the colon into open air, where no tip penalty
could reach it. 44 links gives a 432.5 mm shaft, **495 mm of scope in a 500 mm colon**, and the tip
ends at ~475 mm — **25 mm inside**, still in contact. (Measured off the compiled model, seed 0, not
derived.)

- `SHAFT_LINK_SPACING_M` was also changed from `0.5 / SHAFT_N_LINKS` to a literal **`0.010`**. The
  old expression pinned the shaft to a nominal 500 mm and *re-derived segment length from the link
  count* — so shortening the shaft would have silently thinned the segments to 11.4 mm and
  **softened the shaft**, undoing change (2). Segment length is a physics constant; shaft length is
  `SHAFT_N_LINKS`' job. They are now independent.
- **This is NOT a throughput change — do not repeat it expecting fps.** Measured: 50 → 44 gains
  only ~6% (1,027 → 1,088 mj_step/s), and **contact count is flat at 52.0**. The removed links are
  the free-floating tail *behind* the rollers, which touches nothing; physics cost here is dominated
  by the colon-wall contact solve, not shaft body count. (Change (2) was different — it thinned
  links *inside* the colon, cutting contacts 60 → 52, and that is where its 1.58× came from. Same
  intuition, opposite outcome, because of *where* the links were.)
- **Accepted cost: progress headroom falls 72.5 mm → 12.5 mm.** Headroom is how far `disk_0`
  overshoots `s_goal` (= colon length − `END_CLEARANCE` 100 mm) at termination, and it is the buffer
  that absorbs shaft **buckling** — a buckled shaft consumes more length than the centreline arc, so
  `disk_0`'s arc-`s` falls short of `ring + shaft_length`. At 12.5 mm, heavy buckling could cap
  completing episodes at ~95–99% progress rather than 100%. If that bites, the fix is
  `END_CLEARANCE` 0.10 → 0.13, **not** a further shortening: 42 links puts headroom at **−7.5 mm**,
  making 100% progress outright unreachable. The tension is structural (the scope is nearly as long
  as the colon), and any fix trades tip margin against headroom.
- ⚠️ **This REDEFINES the completion metric.** `shaft_exhausted` now fires ~60 mm of shaft feed
  (~200 steps at max advance) earlier, so completion % rises for reasons that have nothing to do
  with policy skill. **v8_p1_v1's 25.7% completion is not a valid baseline for anything measured
  after 2026-07-13.** Mean progress is also mildly affected (raw progress at termination drops from
  ~120% to ~103% of `s_goal`; both still clip to 100%, so the *clipping artefact* shrinks rather
  than the metric moving).

**Run disposition — note the name reuse.** The original `v8_p1_v1` checkpoints were **discarded** on
2026-07-13 (three physics/termination changes make its value head worthless as a warm start) and its
`runs_sf/` directory deleted on the rig, so Sample Factory starts a **fresh network**. `EXPERIMENT`
was left at `"v8_p1_v1"`, so **the retrain reuses that name** — there are now two distinct runs
called `v8_p1_v1`. The discarded first one is archived at
**`docs/run_archive/v8_p1/v8_p1_v1_run1_pre0713/`** (`config.json`, `sf_log.txt`, TensorBoard
summaries); every number quoted in this section is reproducible from it. Anything in `runs_sf/`
after 2026-07-13 is the *second* run, on the corrected geometry.

⚠️ **Deleting the run directory is what makes it "from scratch."** Sample Factory resumes from an
existing checkpoint in the experiment dir *by default* — reusing the name with the directory intact
silently continues the old policy (that is exactly how v8_p1_v1 ended up with two physics regimes in
one curve, §12 above).

**What to watch on the retrain.** The tell for success is **`avg_tip_stuck` collapsing without
`avg_stuck` ballooning to replace it**. If `stuck` simply takes over the failure share, the tip is
genuinely jamming rather than being cut off mid-bend, and the whole diagnosis above is wrong. Watch
`avg_shaft_exhausted` too, but remember it is now measured against a different boundary.

## 13. Hard-lessons catalogue

**RL cheats and exploits observed (in the wild, this project):**

| Exploit | Where | Countermeasure that worked |
|---|---|---|
| Drag-base-backward + orientation flip | ppo_v3 | 1-DOF slide joint (structurally forbids it) |
| Curl-into-a-ball, punch through walls | ppo_v6 | Contact-force measurement + termination (physics, not reward) |
| Sprint-and-die at force limit | v9_sf | Don't make force a cheap terminal; per-step observable signal |
| Lumen-reward farming (sit and collect) | v14_sf | No standalone per-step scene reward; progress must be high-water-marked |
| Oscillation farming of shaping reward | v17 iter | Stuck metric on high-water mark (`d_max_s`), not raw deltas |
| UFO posture (tip sideways into ring, camera blind) | v17 | tip_contact obs bit + penalty + truncation |
| Quit-early truncation to cap per-step penalties | v7_shaft_v1 | Rebalance W_PROGRESS; watch for reward↑/progress↓ across consecutive logs |
| *(not an exploit — the inverse)* Anti-exploit truncation so tight the correct manoeuvre is impossible | v8_p1_v1 | `tip_stuck` at 50 contact-steps capped in-contact travel at 15 mm, shorter than a bend's contact arc → sharp bends unsolvable at any skill. Window → 150 (§12) |

**Engineering gotchas (do not repeat):**

| Mistake | Lesson |
|---|---|
| Convex-hull mesh collision on hollow tubes | Per-triangle thin-prism decomposition (also: single mesh geoms silently convex-hull — the V-groove needed 2 geoms) |
| `priority` to win a friction contest | Overrides the whole contact set incl. solref — lower the shared default instead |
| Inferring friction combination from slide distance | Read `d.contact[i].friction` directly; the soft solver creeps |
| Hard force gate `×(1−force_norm)` | Zero gradient at high force → "do nothing" optimum |
| Terminal penalties at a different scale to per-step reward | 250× mismatch → KL explosion/NaN |
| `terminated=True` for stuck states | V=0 bootstrap punishes *reaching* the obstacle; use truncation |
| Anti-exploit penalties from step 1 | Bootstrap trap — add only after the policy earns real reward (mean >15–30%) |
| ROLLOUT shorter than the manoeuvre | BPTT window must cover a full ring/bend approach (32→64) |
| `.get("rnn_states")` on SF eval output | SF stores `"new_rnn_states"` — GRU silently zeroed, 52%→2% |
| ent_coef copied from defaults | Calibrate against actual per-step task reward magnitude |
| Centroid in obs or controller | Either breaks IRL validity or removes the learning problem (v4's dilemma) |
| IK/calibration for sim-to-real | Tendon gain varies with shaft bend under load — use domain randomisation |
| Sweeping preload for grip capacity | With stiff solref, preload only guarantees contact exists; contact *area* (flare) is the lever |
| Aim-shaping in the reward | Re-implements analytic control; steering must emerge from observation (the reframe, §5) |
| Local-only curvature check on a multi-bend random centreline | Chained random-axis bends have no memory of earlier segments — 320–750° of total turning routinely folds the path back through itself; check global self-distance, not just per-bend curvature (§11, v7_shaft_v4 seeds 43/34) |
| Truncating on a *proxy* for the failure instead of the failure | "Tip touching wall" ≠ "tip stuck". Contact is mandatory when clearing a bend. Truncate on the thing you actually care about (no new territory), which `stuck` already did (§12) |
| Per-step contact penalty vs. per-step progress reward, uncompared | Always divide them: `W_TIP_PENALTY` (0.001) vs `W_PROGRESS × ADVANCE_RATE_MAX` (0.0012) made bend-clearing net-negative below 83% of max advance. A penalty is only safe if you know its ratio to the reward it competes with (§12) |
| Changing joint density without rescaling stiffness/damping/mass | Effective beam stiffness and damping both scale as `per-joint value × segment length`. The 50→76-link bump compensated stiffness but silently left the shaft 1.5× more damped and 1.5× heavier (§12) |
| Deriving segment length from link count (`spacing = total / N`) | Couples shaft *length* to shaft *stiffness*: shortening the shaft silently thins the segments and softens it. State segment length as a literal; let N set length alone (§12) |
| Assuming fewer bodies = faster physics | Only if those bodies *make contacts*. Removing 6 shaft links behind the rollers (free-floating, zero contacts) gained 6%; removing 26 links from inside the colon cut contacts 60→52 and gained 58%. Check `ncon`, not body count (§12) |
| A scope longer than the colon it drives through | 555 mm of scope in a 500 mm colon put the tip 35 mm *outside* the far end at `shaft_exhausted` — and since `new_territory` reward isn't capped at `s_goal`, the policy was paid to drive into open air where no tip penalty could reach it. Check the terminal geometry, not just the initial (§12) |
| A physics fix bundled with four other changes | v8_p1's 37%→60% jump came from 5 simultaneous changes; joint density's own contribution is unmeasured, and reverting it is now the only way to find out (§12) |
| Resuming a run in the same experiment dir after changing the physics | The step counter continues and the TB curves concatenate, so the run *looks* like one continuous training curve. It isn't. v8_p1_v1's 0–10M and 10–15M halves are different environments (§12) |

## 14. Results summary

| | v5_smooth | v6_dr (700V3) | v7_shaft_v2 | v8_p1_v1 |
|---|---|---|---|---|
| Base advance | kinematic slide | kinematic slide | **physical shaft + rollers** | physical shaft + rollers |
| Depth obs | 48×48, clean | 64×64 + DA3 error-map noise | 64×64 + DA3 error-map noise | 64×64 + DA3 error-map noise |
| State obs | 10-D (incl. force) | 10-D (incl. force) | 9-D (incl. force) | **8-D, no force signal — cable extension** |
| Domain randomisation | none | gains/dead-zone/lag/advance | gains/dead-zone/lag (advance DR removed — real shaft friction replaces it) | same + DR applied to the integral actuator |
| Colon | 1–3 bends, variable length | 700 mm fixed, 2–4 bends ≤150° | 700 mm, then task variants | 500 mm, 4–5 bends |
| Completion | 44% | **93.75%** (80 seeds) | ~90% (`shaft_exhausted`) | 25.7% |
| Mean progress | 89.7% | **96.7%** | ~92% | 63.2% |

**Do not read that last column as a regression against v6/v7.** The task and the observation
are both strictly harder: no force signal at all (v6/v7 got `force_norm`, which no real device
can measure), and a shorter, denser-bend colon. v8_p1_v1's numbers are also from an unconverged
5M-step warm start whose dominant failure mode has since been diagnosed as an environment bug
(§12), not a policy limitation. The honest cross-generation comparison does not exist yet.

## 15. What comes next

The live line is **v8_p1**. v7_shaft is superseded — the v7_shaft_v4 retrain thread listed here
previously was overtaken by v8_p1, which carries the corrected generator forward anyway.

- **Retrain from scratch on the 07-13 changes — LAUNCHED 2026-07-13, RESULT NOT YET SEEN.** All
  three changes (`TIP_STUCK_WINDOW = 150`, 44-link shaft, decoupled segment length) are in the code
  and synced. The old checkpoints were discarded and the run directory deleted, so this is a genuine
  **fresh network** — but it **reuses the name `v8_p1_v1`** (see §12's run-disposition note; the
  discarded original is archived as `v8_p1_v1_run1_pre0713`). Success looks like
  `avg_tip_stuck` collapsing *without* `avg_stuck` rising to replace it; that would confirm the
  bend-clearing diagnosis and should take mean progress well past 63%. The 1.58× throughput
  recovery means a 15M-step budget now costs roughly what 10M did before, so a longer run is
  affordable — and v8_p1_v1's reward had not clearly converged at its step limit.
  **Do not compare its completion % to v8_p1_v1's 25.7%** — the `shaft_exhausted` boundary moved.
- **If progress still stalls: the tip-penalty coupling, not `W_PROGRESS`.** Gate `W_TIP_PENALTY`
  on non-advancement (§12). The code carries an explicit warning against re-doubling `W_PROGRESS`
  a third time.
- **Evaluate properly.** No v8_p1 checkpoint has ever been through `eval_sf.py`. All numbers in
  §12 are *training* statistics. Match v6_dr's protocol (80 seeds × 5 episodes) for a figure that
  is comparable to the table-14 baselines. `eval_sf.py`/`viewer_sf.py` cannot run on Windows —
  use the Linux rig or the WSL2 mirror at `~/mujoco_v3/`.
- **V8 Phase 2 — gravity + anatomical colon.** Layers 2 and 3 of the original V8 plan, still
  unstarted and with **no plan document** (the 2026-07-12 one was deleted on 2026-08-02 — its
  shaft mass and length figures predated the 2026-07-13 retrain and were wrong by ~1.8×).
  Re-scope from live code; current constants are in
  [CURRENT_PLAN.md](CURRENT_PLAN.md) §9. Expect a genuine physics re-tuning pass, not a flag
  flip: every shaft/roller constant in the project was swept under zero gravity.

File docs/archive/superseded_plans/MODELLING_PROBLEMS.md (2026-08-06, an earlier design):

# Modelling Problems — Tendon Actuation, Sim vs Hardware

**Written 2026-07-28.** Self-contained briefing document. It assumes no access to the
repository, so every constant, code path and design decision it relies on is quoted inline.

**Purpose.** We are building a physical colonoscope to deploy an RL policy trained in MuJoCo.
The policy is trained and stable in sim. A sim-to-real gap has been identified in the **tendon
actuation model** that is not a tuning problem but a *structural* modelling problem. This
document states what sim currently models, what the hardware actually does, and where the two
diverge — so the actuation architecture can be redesigned before the next training run.

**Attribution note:** the 25-hinge tendon-driven videoscope tip model described in §1 was
supervisor-provided. The RL environment, shaft, roller feeder, observation design and all
sim-to-real work around it are the author's.

---

## 0. TL;DR

Sim routes its tendons through **the articulating tip only**. Real Bowden cables run the entire
length of a **flexible, continuously-bending shaft**. Consequently:

- In sim, cable length is a **pure kinematic function of tip bend**. It is an exact tip-angle sensor.
- On hardware, proximal reel-in is **tip bend + shaft path length change + sheath compression +
  stretch**, and the shaft term moves independently of the tip.

Everything the policy currently observes about its own articulation (`cmd_x_n`, `cmd_y_n`,
`ten_x_n`, `ten_z_n`) is expressed as a fraction of a **calibrated maximum pull** that exists in
sim and does not exist on the rig. The RL action is likewise an **absolute position setpoint**
scaled by that same constant — not, as is easy to assume, a directional command.

The proposed direction of travel: **isolate the policy from the pull→deflection map entirely**,
by making the action directional/rate-based and closing the low-level loop on cable tension
(force sensors are present on each cable on the rig). This document is the input to that design
discussion, not a decision.

---

## 1. What the simulation currently models

### 1.1 Tip geometry

The articulating tip is a chain of **26 disks / 25 hinge joints**:

| Parameter | Value |
|---|---|
| Disk outer diameter | 9.0 mm |
| Disk spacing | 2.5 mm |
| Tendon hole radius (from centreline) | **3.2 mm** |
| Joints | 25, alternating bend axis |
| Per-joint range | ±10° (0.1745 rad) |
| X-axis joints | 12 → **120°** total |
| Z-axis joints | 13 → **130°** total |

The 12/13 split is an unavoidable consequence of an odd joint count, not a defect. It is the
origin of the per-axis asymmetry in every constant below.

Four tendons at **0°, 90°, 180°, 270°** around the hole circle, named `px`, `pz`, `nx`, `nz`.
They form two antagonistic pairs: `px`/`nx` bend the X axis, `pz`/`nz` bend Z.

### 1.2 Tendon routing — the critical detail

Each tendon is a MuJoCo `<spatial>` tendon threaded through one site per disk:

```python
for name, _angle, rgba in TENDONS:
    w(f'    <spatial name="tendon_{name}" width="...">')
    for disk_idx in range(scope_gen.N_DISKS):        # N_DISKS = 26
        w(f'      <site site="hole_{name}_{disk_idx}"/>')
    w('    </spatial>')
```

`N_DISKS = 26`. **The tendon path begins at tip disk 0 and ends at tip disk 25.** It does not
extend into the shaft, and there is no proximal actuator, sheath, or drive train modelled at all.

Therefore in sim, `data.ten_length` for a given tendon is a **closed-form function of the 25 tip
hinge angles and nothing else**. The shaft can be straight or tied in a knot; the tendon length
does not change.

### 1.3 The flexible shaft (for context)

Behind the tip is a **44-link, 432.5 mm** flexible shaft: pairs of X-hinge/Z-hinge universal
joints (no torsional DOF, matching a real colonoscope), with `shaft_link_0` on a free joint. It is
fed in by an entrance roller/capstan pair that can genuinely slip. Total scope length is 495 mm
inside a 500 mm colon.

**This shaft bends continuously and arbitrarily during an episode — and no tendon passes through
it.** That is the whole problem, stated geometrically.

### 1.4 Calibrated constants

Measured directly via `mj_forward` with all joints on one axis driven to their limit stops
(not analytically derived):

| Constant | Value | Meaning |
|---|---|---|
| `MAX_PULL_X` | **6.795 mm** | single-tendon pull to reach the 120° X limit |
| `MAX_PULL_Z` | **7.361 mm** | single-tendon pull to reach the 130° Z limit |
| `TEN_X_RANGE_M` | **13.380 mm** | `nx − px` length differential at the X limit |
| `TEN_Z_RANGE_M` | **14.495 mm** | `nz − pz` length differential at the Z limit |

Note the differentials are **not** exactly `2 × MAX_PULL` (13.590 / 14.722 would be). The pulled
tendon's shortening and the slack tendon's lengthening differ slightly, because the hole geometry
is not symmetric under bend. Sim already accounts for this small asymmetry by measuring rather
than deriving — worth knowing, because it is a *miniature* version of the hardware problem, and
the fact that sim bothered to measure it shows the effect is real even in the idealised case.

### 1.5 The actuator law

Each tendon has **two** actuators whose forces sum on the same tendon.

**(a) The P+D length servo** — a virtual spring-damper:

```xml
<general name="pull_px" tendon="tendon_px"
         gaintype="fixed" biastype="affine"
         ctrllimited="true"  ctrlrange="-0.006795 0.006795"
         forcelimited="true" forcerange="-80.0 0"
         gainprm="-6000.0 0 0"
         biasprm="<KP*REST_LENGTH> -6000.0 -0.08"/>
```

`ACTUATOR_KP = 6000`, `ACTUATOR_DAMPING = 0.08`. `forcerange="-80 0"` is the one piece of genuine
cable physics present: **force is sign-constrained, so a cable can pull but never push.** Control
input is a target length offset in metres, limited to ±`MAX_PULL`.

**(b) The integral actuator** (added 2026-07-12), a separate actuator on the same tendon:

```xml
<general name="pull_px_i" tendon="tendon_px"
         dyntype="integrator" gaintype="fixed" biastype="none"
         ctrllimited="false"
         forcelimited="true" forcerange="-80.0 0"
         gainprm="-36000.0 0 0"/>
```

`ACTUATOR_KI = 36000` (~6× KP), with anti-windup (freezes within 2 N of the 80 N limit). MuJoCo's
affine bias law has no accumulator, so a true PID cannot be expressed in a single actuator — hence
the second one.

**Why it exists, and why it matters here.** The P+D law alone settles *short* of target, because
zero position error means zero force, and the tip's own joint stiffness (0.5) pushes back. Pure-P
capped achievable bend at **35–45% of nominal** and allowed a slow drift into a folded S-shape.
The integral term drives the tip to **98–99% of commanded bend within 1–2 s**, comfortably inside
a 6–7.5 s episode.

**The consequence for sim-to-real: the integral actuator makes sim's command→deflection map exact
and load-independent.** Push the sim tip against a wall and it still reaches its commanded bend.
That is a deliberate choice — the reasoning at the time was "the rig will run its own encoder PID,
so only the *response characteristics* need to match, not the implementation." That reasoning is
sound **if the rig closes its loop on position**. It is wrong if the rig closes on tension. See §3.

### 1.6 The RL action — an absolute setpoint, not a direction

`action = Box(-1, 1, (3,))` = [X tendon pair, Z tendon pair, roller feed rate]. Per env step
(10 ms; 20 MuJoCo substeps × 0.5 ms, so the control rate is **100 Hz**):

```python
target_x = x * self.max_pull_x                       # absolute target, in metres
vel_x    = self.cmd_x_pair - self.prev_cmd_x
self.cmd_x_pair = clip(
    self.cmd_x_pair + PD_KP * (target_x - self.cmd_x_pair) - PD_KD * vel_x,
    -self.max_pull_x, self.max_pull_x,
)
```

`PD_KP = 0.06`, `PD_KD = 0.30` (heavily over-damped). The pair is driven antagonistically:
`ctrl[px] = +cmd_x_pair`, `ctrl[nx] = −cmd_x_pair`.

**`action[0] = 0.5` means "settle at 50% of maximum X pull".** The gains are slow enough that it
*behaves* rate-like over a handful of steps, which makes it easy to mistake for a directional
command — but its fixed point is an absolute position, scaled by `MAX_PULL_X`. Any claim that the
policy "only outputs a direction" is currently false.

### 1.7 The observation vector

8-D state, alongside a 64×64 depth image from the tip camera:

```
[cmd_x_n, cmd_y_n, ten_x_n, ten_z_n, last_action[0..2], tip_contact]
```

```python
cmd_x_n = self.cmd_x_pair / self.max_pull_x                              # controller setpoint
tl      = self.data.ten_length
ten_x_n = clip((tl[nx] - tl[px]) / TEN_X_RANGE_M, -1.0, 1.0)             # "encoder differential"
ten_z_n = clip((tl[nz] - tl[pz]) / TEN_Z_RANGE_M, -1.0, 1.0)
```

`ten_x_n`/`ten_z_n` were introduced deliberately in V8 Phase 1 to *replace* `force_norm` (summed
contact force) and `net_fx`/`net_fz` (actuator force), on the grounds that those are privileged
sim-only signals with no hardware equivalent, whereas **cable extension maps onto a real linear
encoder on each cable**. The governing design rule was, and remains:

> Only give the policy signals the simulation can model with genuine fidelity — kinematic,
> encoder, and contact-boolean signals. Never feed it force- or friction-derived signals. Sim
> friction is not real friction, so the policy either overfits a fantasy signal or learns to
> ignore it as noise.

**§2 argues that `ten_x_n`/`ten_z_n` fail that same test, for a reason that was missed at the
time.** The rule was applied correctly; the classification of this particular signal was wrong.

### 1.8 What domain randomisation currently covers

Sampled per episode, never observed by the policy:

| Parameter | Range | Applied to |
|---|---|---|
| Tendon gain X / Z | 0.45 – 1.00 | actuator **force** (`gainprm`), both P+D and integral |
| Dead zone X / Z | 0 – 3% of `MAX_PULL` (≈ 0.2 mm) | zero-centred command deadband |
| Command lag | 0 – 2 env steps (0–20 ms) | ring buffer on the effective command |

**Two limitations that matter enormously here, and are easy to miss:**

1. **DR does not randomise the command→deflection map.** The gain scales actuator *force*, and the
   code comment is explicit that this is intentional: *"the endpoint stays reachable at any gain,
   only the force/speed getting there varies."* Combined with the integral actuator, **every
   episode reaches 98–99% of commanded bend regardless of the sampled gain.** The mapping is
   fixed, exact and known in every single training episode. A policy trained here has never once
   encountered a miscalibrated tip.

2. **The dead zone is not backlash.** It is a stateless, symmetric threshold about *zero command*:
   `eff_x = 0 if abs(cmd_x) < dead_x else cmd_x`. It carries no state and models no slack take-up
   on **direction reversal** — which is the dominant Bowden effect. At ≤0.2 mm it is also roughly
   an order of magnitude smaller than realistic Bowden slack.

---

## 2. What the hardware actually does

Six divergences, roughly in decreasing order of severity. The first is structural; the rest are
degrees of "the map is not what sim thinks it is."

### 2.1 Shaft path length contamination — the structural one

Sim's tendon spans the tip only, so cable length is a **pure tip-bend readout**. The real cable
runs from a proximal motor, through ~1.6 m of Bowden sheath, down a shaft that is *itself bending
continuously and in multiple directions*, to the tip.

```
SIM:       [motor: none] ────────────────────────  [tip: 26 disks] → ten_length = f(tip angles)
HARDWARE:  [motor] ══ sheath through flexing 432 mm shaft ══ [tip] → reel-in = f(tip angles, SHAFT PATH, friction, stretch)
```

**Real reel-in = tip articulation + shaft path length change + sheath compression + cable stretch.**

The shaft term is the killer: as the scope advances through a colon, the shaft takes on multiple
bends in different directions. Cable path length changes **with no tip motion whatsoever**. The
policy would read a large `ten_x_n` swing and infer the tip had articulated, when in fact only the
shaft moved.

Note that a **compensating** effect exists in principle: on a real colonoscope the four cables are
routed symmetrically about the shaft's neutral axis, so a pure shaft bend lengthens one side and
shortens the other by *almost* equal amounts, and the antagonistic **differential** cancels much of
it. This is precisely why the differential form was chosen for the obs. But that cancellation
requires the symmetry that the off-centre routing on this rig **does not have** — and it degrades
further with sheath friction, which is direction-dependent and does not cancel.

**The claim this invalidates.** An earlier internal write-up asserted: *"wire is near-inextensible
→ proximal reel-in **is** the tendon length, not an approximation."* Near-inextensibility gives
length *conservation*; it does not give path *invariance*. For a Bowden cable in a bending sheath,
reel-in and tip articulation are simply different quantities. **This is the error at the root of
this document.**

### 2.2 Off-centre routing breaks the differential assumption

The rig's four cables are not at a clean symmetric radius. Consequences:

- The two cables of a pair have **different effective moment arms**, so pull and pay-out are not
  equal and opposite. Commanding `ctrl[px] = +c`, `ctrl[nx] = −c` (sim's exact antagonistic
  mapping) either **slackens** one cable or **over-tensions** it.
- `MAX_PULL` becomes **per-cable**, not per-axis — four different numbers, not two.
- The differential `(nx − px)` is no longer a clean proxy for bend, because the two terms are
  scaled differently by geometry.

Sim models a *0.2 mm* version of this asymmetry (§1.4) and treats it as a fixed measured constant.
The rig's version is larger and configuration-dependent.

### 2.3 Slack and pretension

At **zero commanded bend** the cables must already be tensioned, or they go slack and the tip
flops. Under **large bend**, one side must pay out more than the other takes up (§2.2), so a naive
antagonistic differential drive either creates slack on the outside or fights itself.

Sim never models slack. `forcerange="-80 0"` means a sim tendon carrying no load simply produces
zero force — the qualitative behaviour is right (a cable cannot push) but there is no slack
*state*, no take-up transient, and no pretension.

### 2.4 Sheath friction, hysteresis, backlash

Bowden transmission is **hysteretic**: pull to a position, reverse, and the tip does not retrace
the same path. Friction in the sheath is direction-dependent and load-dependent, and it *increases
with shaft curvature* — so it gets worse exactly when the scope is in a tight bend and steering
matters most.

Sim models **none** of this. The 0–3% dead zone is stateless and zero-centred (§1.8), which is not
backlash in any meaningful sense.

### 2.5 The map is non-linear and configuration-dependent

Sim: one fixed `MAX_PULL` per axis, measured once, exact forever. Hardware: the pull→deflection
relationship varies with shaft configuration, insertion depth, load, temperature and wear. It
cannot be calibrated once and trusted, and it **cannot be observed** — there is no sensor that
reports the shaft's shape, and the tip camera cannot see the shaft.

This is the user's original framing, and it is the correct one: *"I can't know the bend of the
shaft in real life as it can't see it, and it might make multiple bends in different directions."*

### 2.6 Load dependence

A subtler asymmetry, in the opposite direction to the others. Sim's integral actuator **rejects
disturbance**: press the tip against a wall and it still reaches commanded bend. Whether the
hardware does the same depends entirely on the low-level loop:

- **Position/encoder control** → stiff, disturbance-rejecting → sim is approximately right.
- **Tension control** → compliant, load-dependent → the tip yields on contact, and sim is wrong
  in a way that flatters the policy.

Since the tip is in wall contact for much of a real episode, this is not a corner case.

---

## 3. The proposed direction, and the open questions

### 3.1 The proposal

The rig has **force sensors on every cable**. The idea under consideration:

1. Hold all four cables at a controlled tension — eliminating slack, pretension and backlash
   *mechanically*, at the low level, where the sensors are.
2. Have the policy output only a **direction / rate**, never an absolute pull.
3. Let the policy close the loop **visually**: it sees the lumen off-centre in the depth image,
   commands "more +X", and watches it centre.

**Why this is the strongest version of the fix.** A visual servo is *invariant* to the
pull→deflection map. The policy never needs to know that 5 mm = 40°; it only needs the response to
be **monotone in the commanded direction**. Every problem in §2 degrades a *calibration*; none of
them break *monotonicity*. Editing the observation vector (removing `ten_*` or the `max_pull`
normalisation) only shaves the edges off the problem — it leaves an absolute-setpoint action still
scaled by a constant that does not exist on the rig.

### 3.2 What this would require changing in sim

- **Action semantics: absolute setpoint → rate.** `action[0]` becomes a *rate of change* of bend,
  integrated by the controller, rather than a target scaled by `MAX_PULL_X`. This is a real change
  (§1.6), not a relabelling.
- **Observation: remove the channels that encode the calibrated map.** `cmd_x_n`/`cmd_y_n` are
  `cmd / max_pull`; `ten_x_n`/`ten_z_n` are the contaminated encoder differential. Candidate
  reductions: 8-D → 6-D (drop `ten_*`) or 8-D → 4-D (drop both, leaving `last_action[0..2]` +
  `tip_contact`). **Any obs-shape change forces a from-scratch retrain** — acceptable, since the
  next planned phase requires one anyway.
- **Possibly the actuator law.** If the rig is tension-controlled, sim's integral actuator
  (§1.5) enforces an exactness the hardware will not have, and modelling a compliant,
  load-dependent tip may mean revisiting it. Note the tension: the integral term exists to fix a
  real instability (S-shape folding, 35–45% range cap). It cannot simply be deleted.
- **Widen DR to cover the map itself.** Currently the map is exact in every episode (§1.8). At
  minimum: randomise the command→deflection gain on the *target* rather than the force; make the
  dead zone a state-carrying backlash model with slack take-up on reversal; randomise per-cable
  rather than per-axis asymmetry.

### 3.3 Open questions

1. **Which low-level loop will the rig run?** Tension-differential (compliant tip, fully
   routing-agnostic, load-dependent bend) or position-rate with a tension floor (stiff tip, holds
   bend against wall load, closer to current sim)? This determines whether the integral actuator
   stays. It is the single highest-leverage unresolved question.

2. **Can a rate-command policy dead-reckon its articulation state?** With an absolute setpoint,
   `cmd_x_n` tells the policy where the tip is. With a rate command and `cmd_*` removed from the
   obs, the policy must integrate its own action history through a GRU (1 layer, 512 hidden,
   64-step BPTT window) across episodes of 600–2300 steps. That may be fine — vision provides the
   feedback — but it is unproven and is the main behavioural risk of the 4-D obs.

3. **How much do the existing obs channels actually contribute?** Cheaply answerable *without any
   retrain*: zero out `ten_x_n`/`ten_z_n` at eval time on the current stable checkpoint and measure
   the drop in mean progress across the standard 80 seeds × 5 episodes. If it barely moves, the
   channels were not load-bearing and dropping them is low-risk. **This experiment should precede
   the design decision, not follow it.**

4. **Should the sim's cables be routed down the shaft for real?** The high-fidelity fix is to
   thread the four tendon paths through sites on all 44 shaft links, so `ten_length` genuinely
   includes shaft path change. This would make the signal honest rather than removing it — but it
   changes the actuator transmission physics and would force a full re-tune of shaft and roller
   constants, all of which were swept under the current model.

5. **Should cable tension enter the observation, now that sensors exist?** **Recommendation: no.**
   Tension at the motor is dominated by sheath friction, which sim does not model faithfully.
   Owning a sensor does not make the signal sim-modellable — this is exactly the trap that retired
   `force_norm` and `net_fx`/`net_fz` in Phase 1. Use the force sensors for the low-level tension
   loop, which is a hardware control problem and the right job for them, and keep them out of the
   policy's input.

---

## 4. Summary table

| Aspect | Sim today | Hardware reality | Severity |
|---|---|---|---|
| Cable routing | Tip disks only (26 sites) | Full 1.6 m through a bending shaft | **Structural** |
| `ten_length` meaning | Exact tip-bend kinematics | Tip bend + shaft path + friction + stretch | **Structural** |
| Pull→deflection map | Fixed, exact, known, load-independent | Variable, non-linear, unobservable | **High** |
| Antagonist pair | Balanced, `ctrl[nx] = −ctrl[px]` | Unbalanced — off-centre routing | **High** |
| Slack / pretension | Not modelled (force-limited to pull-only) | Must be actively managed | **High** |
| Backlash / hysteresis | Not modelled (stateless 0.2 mm deadband) | Significant, curvature-dependent | **High** |
| RL action | Absolute setpoint × `MAX_PULL` | — (the constant does not exist) | **High** |
| Disturbance rejection | Total (integral actuator, 98–99%) | Depends on low-level loop choice | Medium |
| DR coverage of the map | None — exact in every episode | — | Medium |

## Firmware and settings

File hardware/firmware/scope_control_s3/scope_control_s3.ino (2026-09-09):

/*
  scope_control_s3.ino
  ============================================================================
  RUNTIME control firmware for the autonomous-endoscope rig (ESP32-S3).

  This is the deployment sibling of the bring-up sketches in this folder. It is
  NOT interactive and NOT a calibration tool -- it speaks the binary
  scope_link protocol to the WSL ROS node `scope_link` and drives the four
  tendon servos to follow the policy's steering setpoints, with a safety
  governor on top.

      scope_link (WSL)  <--UART 921600, COBS+CRC16-->  this firmware
        /scope/action  ->  SETPOINT  ->  [normalised -1..1 -> ticks (asymmetric
                                          per-direction MAX_PULL), SYNC WRITE the pairs]
        /scope/command ->  ENABLE / DISABLE / CLEAR_SAFETY / ESTOP
                       <-  TELEMETRY (50 Hz): seq echo, tip_contact, tension,
                                              servo pos + current, safety state

  Protocol is defined once in
    deploy/ros2_ws/src/scope_control/scope_control/scope_link_proto.py
  -- keep this file in lockstep and bump PROTO_VERSION together.

  --------------------------------------------------------------- BOARD
  Board:            "ESP32S3 Dev Module"
  USB CDC On Boot:  Disabled     -> Serial == UART0 == the CP2102 "UART" jack.
  FLASH via:        the NATIVE-USB jack (leave the CP2102 jack forwarded to WSL
                    via usbipd for the protocol link -- see the ROS 2 deployment
                    memory).
  Serial (UART0):   921600 8N1  -- the scope_link protocol. Do NOT Serial.print
                    plain text here; all human-readable output goes out as
                    T_LOG frames (fwlog()).

  ----------------------------------------------------------------- PINS
    Servo bus (UART1, 1 Mbaud 8N1)   -- same as scope_bringup_s3.ino
      GPIO17  TX -> FE-URT-2 RX
      GPIO18  RX <- FE-URT-2 TX
      GND        -- common with FE-URT-2 and the servo supply

    HX711 cable-tension amps (bit-banged, shared clock)
      GPIO14  SCK  -> all four HX711 PD_SCK
      DOUT, IN SERVO ORDER (see hardware/bringup/measured_constants.md +
      the "HX711 sensor <-> servo mapping" memo -- the sensors are NOT wired
      in servo-ID order):
        servo 1 -> GPIO10
        servo 2 -> GPIO11
        servo 3 -> GPIO12
        servo 4 -> GPIO13
      HX711 RATE pin: tie HIGH for 80 SPS. If left low (default) you get
      10 SPS and the tension safety path is only ~10 Hz -- the fast path then
      leans on servo current instead. Set HX_RATE_PIN below if you wire it.

    E-stop authority (safety core owns this alone -- a bus torque-off is NOT a
    safety stop, see the deployment memory)
      ESTOP_MOSFET_PIN  -> gate of the high-side switch in the SERVO SUPPLY.
      *** TODO: confirm the pin and the polarity against the actual board. ***

    Tip-contact flex sensor  -> voltage divider -> ADC pin.
      *** TODO: not wired / not calibrated yet. TIP_CONTACT_FORCE_ZERO keeps
          the reported flag at 0 until then. ***

  ------------------------------------------------------ WHAT IS STILL A GUESS
  Marked "TODO/VERIFY" below and safe to run only on the bench until checked:
    - AXIS_SERVO / AXIS_INVERT  (which servo pair is cmd_x vs cmd_y, and the
                                 steering sign -- watch the image and flip)
    - ESTOP_MOSFET_PIN + ESTOP_ENABLE_LEVEL
    - CURRENT_LSB_MA        (STS3032 REG 69 scale)
  MAXPULL_DEFAULT is the measured `bend` result (2026-09-09); scope_link's
  CONFIG frame overrides it from scope_params.yaml, so it need not be exact.
    - TIP_CONTACT_* pins/threshold
*/

#include <string.h>
#include <stdio.h>
#include <math.h>

// ======================================================================
//  CONFIG
// ======================================================================

static const uint8_t  PROTO_VERSION = 2;   // must match scope_link_proto.py

// ---- pins ----
static const int8_t  BUS_TX_PIN = 17;
static const int8_t  BUS_RX_PIN = 18;
static const uint8_t HX_SCK     = 14;
static const uint8_t HX_DT_FOR_SERVO[4] = { 10, 11, 12, 13 };  // index = servo (id-1)
static const int8_t  HX_RATE_PIN = -1;      // set to the GPIO if you wire RATE high (80 SPS)

static const int8_t  ESTOP_MOSFET_PIN   = 21;    // TODO verify
static const uint8_t ESTOP_ENABLE_LEVEL = HIGH;  // level that ENABLES the servo supply

static const int8_t  TIP_CONTACT_PIN = 4;        // ADC1_CH3; TODO verify
static const bool     TIP_CONTACT_FORCE_ZERO = true;   // sensor not wired yet
static const int      TIP_CONTACT_ADC_THRESHOLD = 1800; // TODO calibrate

// ---- tendon geometry ----
static const int16_t ZERO_TICK     = 2048;                // EEPROM zero from `setzero`
static const int16_t SEAM          = 100;                 // stay this far from the 0/4095 wrap
static const int16_t MAX_ABS_TICKS_FROM_ZERO = 950;       // hard outer clamp (~83 deg); a bad CONFIG can't drive past this

// Per-axis, per-direction bend limits in ENCODER TICKS -- the rig's + and -
// directions are ASYMMETRIC (measured 2026-09-09 with `bend`;
// hardware/bringup/measured_constants.md). The normalised command -1..+1 is
// mapped to ticks with these. Compiled defaults; CONFIG overrides at runtime.
// Index [axis][0] = + direction, [axis][1] = - direction.
static const uint16_t MAXPULL_DEFAULT[2][2] = { { 724, 681 }, { 840, 603 } };
static const float    MAXPULL_HEADROOM_DEFAULT = 0.9f;    // bend was measured tip-free; friction reduces it

// Axis -> antagonistic servo pair. AXIS_SERVO[axis] = { pull+, pull- }.
// axis 0 = ScopeAction.cmd_x_n, axis 1 = cmd_y_n.
// The two servos of a pair share a PULL_SIGN (measured 2026-09-08).
static const uint8_t AXIS_SERVO[2][2] = { { 1, 3 }, { 2, 4 } };   // TODO verify which is X vs Z
static const bool    AXIS_INVERT[2]   = { false, false };         // flip if an axis steers backwards
static const int8_t  PULL_SIGN[5]     = { 0, -1, +1, -1, +1 };    // [servo id]; 1&3 pull on -, 2&4 on +

// ---- servo motion ----
static const uint16_t SERVO_SPEED = 3000;   // per-setpoint interpolation speed (0 = max)
static const uint8_t  SERVO_ACC   = 0;      // acceleration (0 = disabled)
// Firmware-side slew clamp: the most any servo goal may move per motor cycle.
// A second line of defence against a policy glitch or a garbled-but-valid
// setpoint -- bounds the tip speed no matter what is commanded.
static const int16_t  MAX_TICKS_PER_CYCLE = 8;   // @200 Hz -> ~1600 ticks/s ~= 140 deg/s

// ---- safety (compiled defaults; CONFIG frame overrides at runtime) ----
static const float    CURRENT_LSB_MA = 6.5f;     // STS3032 REG 69 scale; TODO verify

struct SafetyCfg {
  float    current_limit_ma  = 800.0f;
  float    tension_limit_g   = 250.0f;
  uint16_t spike_debounce_ms = 20;
  uint16_t comms_timeout_ms  = 120;
  uint16_t motor_hz          = 200;
  uint16_t telem_hz          = 50;
  uint16_t maxpull[2][2]     = { { MAXPULL_DEFAULT[0][0], MAXPULL_DEFAULT[0][1] },
                                 { MAXPULL_DEFAULT[1][0], MAXPULL_DEFAULT[1][1] } };
  float    maxpull_headroom  = MAXPULL_HEADROOM_DEFAULT;
};
static SafetyCfg cfg;

// applied tick limit for axis (0=x,1=z), direction (positive?), headroom folded in
static int16_t appliedMaxPull(uint8_t axis, bool positive) {
  float raw = (float)cfg.maxpull[axis][positive ? 0 : 1];
  int16_t v = (int16_t)lroundf(raw * cfg.maxpull_headroom);
  if (v < 1) v = 1;
  if (v > MAX_ABS_TICKS_FROM_ZERO) v = MAX_ABS_TICKS_FROM_ZERO;
  return v;
}

// ---- HX711 tension calibration (servo order) ----
// counts/gram is one shared factor (hardware/bringup/measured_constants.md).
static const float HX_COUNTS_PER_GRAM = 1105.0488f;
// no-load offsets, RE-ORDERED into servo order from the GPIO-labelled table
// (ch1/GPIO13 = servo 4, ... ch4/GPIO10 = servo 1):
static const long  HX_NOLOAD[4] = {
  -55713,   // servo 1  (GPIO10, was "ch4")
  -73492,   // servo 2  (GPIO11, was "ch3")
  -62355,   // servo 3  (GPIO12, was "ch2")
  -56125,   // servo 4  (GPIO13, was "ch1")
};

// ======================================================================
//  PROTOCOL: message types, framing (COBS + CRC-16/CCITT-FALSE)
// ======================================================================

enum : uint8_t {
  T_SETPOINT  = 0x01,
  T_CONFIG    = 0x02,
  T_COMMAND   = 0x03,
  T_PING      = 0x04,
  T_TELEMETRY = 0x81,
  T_LOG       = 0x82,
  T_PONG      = 0x84,
  T_HELLO     = 0x85,
};

// ScopeCommand values
enum : uint8_t { CMD_DISABLE = 0, CMD_ENABLE = 1, CMD_CLEAR_SAFETY = 2, CMD_ESTOP = 3 };

// telemetry flag bits
static const uint8_t FLAG_TIP_CONTACT  = 0x01;
static const uint8_t FLAG_SAFETY_SHIFT = 1;
static const uint8_t FLAG_SAFETY_MASK  = 0x03;
static const uint8_t FLAG_ENABLED      = 0x08;

// safety_state values (must match scope_msgs/ScopeTelemetry)
enum : uint8_t { SAFETY_OK = 0, SAFETY_CLAMP = 1, SAFETY_HOLD = 2, SAFETY_ESTOP = 3 };

// log levels
enum : uint8_t { LOG_DBG = 0, LOG_INFO = 1, LOG_WARN = 2, LOG_ERR = 3 };

static uint16_t crc16(const uint8_t* d, size_t n) {
  uint16_t crc = 0xFFFF;
  for (size_t i = 0; i < n; i++) {
    crc ^= (uint16_t)d[i] << 8;
    for (int b = 0; b < 8; b++)
      crc = (crc & 0x8000) ? (uint16_t)((crc << 1) ^ 0x1021) : (uint16_t)(crc << 1);
  }
  return crc;
}

// COBS encode: out must hold n + n/254 + 2 bytes. Returns encoded length.
static size_t cobsEncode(const uint8_t* in, size_t n, uint8_t* out) {
  size_t codeIdx = 0, w = 1;
  uint8_t code = 1;
  for (size_t i = 0; i < n; i++) {
    if (in[i] != 0) {
      out[w++] = in[i];
      if (++code == 0xFF) { out[codeIdx] = code; codeIdx = w++; code = 1; }
    } else {
      out[codeIdx] = code; codeIdx = w++; code = 1;
    }
  }
  out[codeIdx] = code;
  return w;
}

// COBS decode. Returns decoded length, or -1 on a malformed segment.
static int cobsDecode(const uint8_t* in, size_t n, uint8_t* out, size_t outCap) {
  size_t r = 0, w = 0;
  while (r < n) {
    uint8_t code = in[r++];
    if (code == 0) return -1;
    for (uint8_t i = 1; i < code; i++) {
      if (r >= n || w >= outCap) return -1;
      out[w++] = in[r++];
    }
    if (code != 0xFF && r < n) {
      if (w >= outCap) return -1;
      out[w++] = 0;
    }
  }
  return (int)w;
}

static void sendFrame(uint8_t type, const uint8_t* payload, size_t plen) {
  uint8_t body[132];
  if (plen > sizeof(body) - 3) return;
  body[0] = type;
  memcpy(body + 1, payload, plen);
  uint16_t c = crc16(body, 1 + plen);
  body[1 + plen] = (uint8_t)(c & 0xFF);
  body[2 + plen] = (uint8_t)(c >> 8);
  uint8_t framed[160];
  size_t fl = cobsEncode(body, plen + 3, framed);
  framed[fl++] = 0x00;
  Serial.write(framed, fl);
}

static void fwlog(uint8_t level, const char* msg) {
  uint8_t buf[120];
  buf[0] = level;
  size_t n = strlen(msg);
  if (n > sizeof(buf) - 1) n = sizeof(buf) - 1;
  memcpy(buf + 1, msg, n);
  sendFrame(T_LOG, buf, n + 1);
}

// little-endian scalar readers/writers (ESP32 is LE; payloads use "<" layout)
static float    rdF32(const uint8_t* p) { float v; memcpy(&v, p, 4); return v; }
static uint32_t rdU32(const uint8_t* p) { uint32_t v; memcpy(&v, p, 4); return v; }
static uint16_t rdU16(const uint8_t* p) { uint16_t v; memcpy(&v, p, 2); return v; }
static void wrF32(uint8_t* p, float v)    { memcpy(p, &v, 4); }
static void wrU32(uint8_t* p, uint32_t v) { memcpy(p, &v, 4); }
static void wrU16(uint8_t* p, uint16_t v) { memcpy(p, &v, 2); }
static void wrI16(uint8_t* p, int16_t v)  { memcpy(p, &v, 2); }

// ======================================================================
//  SERVO BUS (Feetech SCS / Dynamixel 1.0 framing) -- from scope_bringup_s3
// ======================================================================

static const uint8_t BROADCAST_ID   = 0xFE;
static const uint8_t INST_PING       = 0x01;
static const uint8_t INST_READ       = 0x02;
static const uint8_t INST_WRITE      = 0x03;
static const uint8_t INST_SYNC_WRITE = 0x83;

static const uint8_t REG_TORQUE_EN   = 40;
static const uint8_t REG_ACC         = 41;   // 7-byte block: acc,posL,posH,timeL,timeH,spdL,spdH
static const uint8_t REG_PRESENT_POS = 56;
static const uint8_t REG_PRESENT_LD  = 60;
static const uint8_t REG_CURRENT     = 69;

static uint8_t sbTx[64], sbRx[64];
static uint8_t sbTxLen = 0;

static void busOpen() {
  Serial1.end();
  Serial1.setRxBufferSize(256);
  Serial1.begin(1000000, SERIAL_8N1, BUS_RX_PIN, BUS_TX_PIN);
  delay(5);
  while (Serial1.read() != -1) {}
}

static void sbSend(uint8_t id, uint8_t inst, const uint8_t* params, uint8_t nParams) {
  uint8_t sum = id + (uint8_t)(nParams + 2) + inst;
  sbTx[0] = 0xFF; sbTx[1] = 0xFF; sbTx[2] = id;
  sbTx[3] = nParams + 2; sbTx[4] = inst;
  for (uint8_t i = 0; i < nParams; i++) { sbTx[5 + i] = params[i]; sum += params[i]; }
  sbTx[5 + nParams] = ~sum;
  sbTxLen = 6 + nParams;
  while (Serial1.read() != -1) {}
  Serial1.write(sbTx, sbTxLen);
  Serial1.flush();
}

// Read until `want` bytes are in, or `timeoutMs` elapses. Returns as soon as it
// has enough -- it does NOT wait for a quiet gap (that cost the bring-up tool
// ~4 ms per transaction, which the 200 Hz motor loop cannot afford).
static uint8_t sbCollectN(uint8_t want, uint16_t timeoutMs) {
  uint8_t n = 0;
  unsigned long t0 = millis();
  while (n < want && n < sizeof(sbRx) && (millis() - t0) < timeoutMs) {
    int c = Serial1.read();
    if (c >= 0) sbRx[n++] = (uint8_t)c;
  }
  return n;
}

// find a checksum-valid status packet from `id` carrying nParams bytes, skipping our echo
static bool sbParse(uint8_t id, uint8_t rxLen, uint8_t* params, uint8_t nParams) {
  uint8_t start = 0;
  if (rxLen >= sbTxLen && memcmp(sbRx, sbTx, sbTxLen) == 0) start = sbTxLen;
  uint8_t total = nParams + 6;
  for (int i = start; i + total <= rxLen; i++) {
    if (sbRx[i] != 0xFF || sbRx[i + 1] != 0xFF) continue;
    if (sbRx[i + 2] != id || sbRx[i + 3] != nParams + 2) continue;
    uint8_t sum = 0;
    for (uint8_t k = 2; k <= nParams + 4; k++) sum += sbRx[i + k];
    if ((uint8_t)(~sum) != sbRx[i + nParams + 5]) continue;
    for (uint8_t k = 0; k < nParams; k++) params[k] = sbRx[i + 5 + k];
    return true;
  }
  return false;
}

// expected reply length = adapter echo (sbTxLen) + status packet (6 + nParams)
static const uint16_t SB_TIMEOUT_MS = 3;

static bool sbPing(uint8_t id) {
  sbSend(id, INST_PING, nullptr, 0);
  return sbParse(id, sbCollectN(sbTxLen + 6, SB_TIMEOUT_MS), nullptr, 0);
}

static bool sbRead16(uint8_t id, uint8_t addr, long* out) {
  uint8_t p[2] = { addr, 2 }, v[2];
  sbSend(id, INST_READ, p, 2);
  if (!sbParse(id, sbCollectN(sbTxLen + 8, SB_TIMEOUT_MS), v, 2)) return false;
  *out = (long)((uint16_t)v[0] | ((uint16_t)v[1] << 8));
  return true;
}

static bool sbWrite8(uint8_t id, uint8_t addr, uint8_t val) {
  uint8_t p[2] = { addr, val };
  sbSend(id, INST_WRITE, p, 2);
  if (id == BROADCAST_ID) return true;
  return sbParse(id, sbCollectN(sbTxLen + 6, SB_TIMEOUT_MS), nullptr, 0);
}

static bool sbWritePos1(uint8_t id, int16_t pos, uint16_t spd, uint8_t acc) {
  if (pos < 0) pos = 0;
  if (pos > 4095) pos = 4095;
  uint8_t p[8] = { REG_ACC, acc,
                   (uint8_t)(pos & 0xFF), (uint8_t)((pos >> 8) & 0xFF),
                   0, 0,
                   (uint8_t)(spd & 0xFF), (uint8_t)((spd >> 8) & 0xFF) };
  sbSend(id, INST_WRITE, p, 8);
  return sbParse(id, sbCollectN(sbTxLen + 6, SB_TIMEOUT_MS), nullptr, 0);
}

// One packet, all four servos start together. goal indexed by servo id 1..4.
static void sbSyncWritePos4(const int16_t goal[5], uint16_t spd, uint8_t acc) {
  const uint8_t L = 7, N = 4;
  uint8_t buf[64];
  uint8_t n = 0;
  buf[n++] = 0xFF; buf[n++] = 0xFF; buf[n++] = BROADCAST_ID;
  buf[n++] = (L + 1) * N + 4;            // LEN
  buf[n++] = INST_SYNC_WRITE;
  buf[n++] = REG_ACC;                     // start address
  buf[n++] = L;
  uint8_t sum = BROADCAST_ID + buf[3] + INST_SYNC_WRITE + REG_ACC + L;
  for (uint8_t id = 1; id <= 4; id++) {
    int16_t p = goal[id];
    if (p < 0) p = 0;
    if (p > 4095) p = 4095;
    const uint8_t rec[8] = { id, acc,
                             (uint8_t)(p & 0xFF), (uint8_t)((p >> 8) & 0xFF),
                             0, 0,
                             (uint8_t)(spd & 0xFF), (uint8_t)((spd >> 8) & 0xFF) };
    for (uint8_t k = 0; k < 8; k++) { buf[n++] = rec[k]; sum += rec[k]; }
  }
  buf[n++] = ~sum;
  while (Serial1.read() != -1) {}
  Serial1.write(buf, n);
  Serial1.flush();
}

// ======================================================================
//  HX711 (non-blocking: only reads when all four DOUT are ready)
// ======================================================================

static long hxRaw[4] = { 0, 0, 0, 0 };       // servo order
static float hxGrams[4] = { 0, 0, 0, 0 };

static bool hxAllReady() {
  for (uint8_t s = 0; s < 4; s++)
    if (digitalRead(HX_DT_FOR_SERVO[s]) != LOW) return false;
  return true;
}

// ~125 us with interrupts off. Call only when hxAllReady().
static void hxReadNow() {
  uint32_t v[4] = { 0, 0, 0, 0 };
  noInterrupts();
  for (uint8_t i = 0; i < 24; i++) {
    digitalWrite(HX_SCK, HIGH);
    delayMicroseconds(1);
    for (uint8_t s = 0; s < 4; s++)
      v[s] = (v[s] << 1) | (digitalRead(HX_DT_FOR_SERVO[s]) ? 1u : 0u);
    digitalWrite(HX_SCK, LOW);
    delayMicroseconds(1);
  }
  digitalWrite(HX_SCK, HIGH); delayMicroseconds(1);   // 25th pulse: next = ch A gain 128
  digitalWrite(HX_SCK, LOW);  delayMicroseconds(1);
  interrupts();
  for (uint8_t s = 0; s < 4; s++) {
    if (v[s] & 0x800000) v[s] |= 0xFF000000;
    hxRaw[s]   = (long)(int32_t)v[s];
    hxGrams[s] = (hxRaw[s] - HX_NOLOAD[s]) / HX_COUNTS_PER_GRAM;
  }
}

// ======================================================================
//  STATE
// ======================================================================

enum SysState : uint8_t { ST_BOOT, ST_HOLD, ST_RUN, ST_ESTOP };
static SysState g_state = ST_BOOT;
static bool     g_enableIntent = false;   // operator wants RUN
static uint8_t  g_holdReason   = 4;       // 0 none, 1 comms, 2 current, 3 tension, 4 boot/disable
static bool     g_allServos    = false;

// latest setpoint from the host: NORMALISED command per pair, -1..+1
static float    g_setXn = 0.0f, g_setYn = 0.0f;
static uint32_t g_setSeq  = 0;
static uint32_t g_lastSetpointMs = 0;

// per-servo working state (index by id: [1..4])
static int16_t g_goalTicks[5]   = { 0, ZERO_TICK, ZERO_TICK, ZERO_TICK, ZERO_TICK };  // slew-limited target
static int16_t g_holdTicks[5]   = { 0, ZERO_TICK, ZERO_TICK, ZERO_TICK, ZERO_TICK };
static int16_t g_presentTicks[5]= { 0, ZERO_TICK, ZERO_TICK, ZERO_TICK, ZERO_TICK };
static int16_t g_currentMa[5]   = { 0, 0, 0, 0, 0 };
static int16_t g_loadRaw[5]     = { 0, 0, 0, 0, 0 };

// safety debounce: millis() a channel first went over-limit (0 = not over)
static uint32_t g_curOverSince[5] = { 0, 0, 0, 0, 0 };
static uint32_t g_tenOverSince[5] = { 0, 0, 0, 0, 0 };

static bool g_tipContact = false;

static uint8_t safetyStateForTelem() {
  if (g_state == ST_ESTOP) return SAFETY_ESTOP;
  if (g_state == ST_HOLD)  return SAFETY_HOLD;
  return SAFETY_OK;
}

static void servoSupply(bool enable) {
  if (ESTOP_MOSFET_PIN >= 0)
    digitalWrite(ESTOP_MOSFET_PIN, enable ? ESTOP_ENABLE_LEVEL : !ESTOP_ENABLE_LEVEL);
}

// ---- state transitions ----

static void captureHold() {
  for (uint8_t id = 1; id <= 4; id++) g_holdTicks[id] = g_presentTicks[id];
}

static void enterHold(uint8_t reason) {
  if (g_state == ST_RUN) captureHold();
  g_state = ST_HOLD;
  g_holdReason = reason;
  for (uint8_t id = 1; id <= 4; id++) g_goalTicks[id] = g_holdTicks[id];
  const char* r = reason == 1 ? "comms timeout" : reason == 2 ? "servo current" :
                  reason == 3 ? "cable tension" : "disable";
  char m[48]; snprintf(m, sizeof(m), "SAFE_HOLD (%s)", r);
  fwlog(LOG_WARN, m);
}

static void enterRun() {
  for (uint8_t id = 1; id <= 4; id++) g_goalTicks[id] = g_presentTicks[id];  // start from where we are
  g_state = ST_RUN;
  fwlog(LOG_INFO, "RUN");
}

static void enterEstop() {
  servoSupply(false);
  g_state = ST_ESTOP;
  g_enableIntent = false;
  fwlog(LOG_ERR, "E-STOP: servo supply cut");
}

static void clearSafety() {
  if (g_state == ST_ESTOP) {
    servoSupply(true);
    delay(300);                       // let the servos boot
    busOpen();
    for (uint8_t id = 1; id <= 4; id++) {
      long p;
      if (sbRead16(id, REG_PRESENT_POS, &p)) {
        g_presentTicks[id] = (int16_t)p;
        g_holdTicks[id] = (int16_t)p;
        sbWritePos1(id, (int16_t)p, 200, 10);
        sbWrite8(id, REG_TORQUE_EN, 1);
      }
    }
  }
  g_holdReason = 0;
  if (g_state != ST_ESTOP) enterHold(0); else { g_state = ST_HOLD; g_holdReason = 4; }
  fwlog(LOG_INFO, "safety cleared -> SAFE_HOLD (send ENABLE to resume)");
}

// ======================================================================
//  COMMAND / CONFIG / SETPOINT handlers
// ======================================================================

static void onSetpoint(const uint8_t* p) {
  g_setXn = rdF32(p);
  g_setYn = rdF32(p + 4);
  g_setSeq  = rdU32(p + 8);
  g_lastSetpointMs = millis();
}
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
void loop() {
  uint32_t now = millis();
  static uint32_t tMotor = 0, tDiag = 0, tTelem = 0;

  pumpSerial();

  const uint32_t motorPeriod = 1000UL / cfg.motor_hz;
  const uint32_t telemPeriod = 1000UL / cfg.telem_hz;

  if (now - tMotor >= motorPeriod) { tMotor = now; motorTick(); }
  if (now - tDiag  >= motorPeriod) { tDiag  = now; diagPoll(); }   // one servo/cycle -> each @ motor_hz/4
  tensionPoll();                                                    // effective rate = HX711 SPS
  tipPoll();
  commsWatchdog(now);
  if (now - tTelem >= telemPeriod) { tTelem = now; sendTelemetry(); }
}

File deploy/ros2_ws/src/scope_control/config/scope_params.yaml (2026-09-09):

# Parameters for the deployment control loop.
#
# Load with:  ros2 run scope_control policy_node --ros-args --params-file <this>
# or via the launch file (once it exists). `/**` applies to the node whatever
# namespace it is pushed into (the launch file puts it under /scope).

/**:
  ros__parameters:

    # ---- trained-checkpoint contract -------------------------------------
    experiment: "v8_p1_v1"

    # Directory containing sf_encoder.py (the custom encoder the checkpoint was
    # trained with). On the WSL mirror:
    nav_code_dir: "/home/lukec/mujoco_v3/navigation/v8_p1"

    # Point at EITHER a checkpoint_p0 folder / a specific best_*.pth
    # (checkpoint_dir), OR a directory that contains runs_sf/ (checkpoint_root).
    # checkpoint_dir wins if both are set.
    checkpoint_dir: ""
    checkpoint_root: "/home/lukec/mujoco_v3/navigation/v8_p1"

    device: "cpu"           # the net is tiny; CPU is deliberate (see policy_runner.py)
    mock_policy: false       # true -> emit zero actions, skip torch/SF (bench bring-up)

    # ---- observation geometry (MUST match the trained env) --------------
    depth_height: 54
    depth_width: 96
    state_dim: 6

    # ---- PD command shaper --------------------------------------------
    # Fitted at 25 Hz by navigation/v9/diagnostics/pd_rate_rescale.py.
    # A x4 arithmetic rescale is UNSTABLE (|z| = 1.337). Do not touch without
    # re-fitting against the wall-clock step response.
    pd_kp: 0.1803
    pd_kd: 0.0475

    # MAX_PULL is NOT here -- policy_node runs the shaper normalised. The real
    # (asymmetric) encoder limits live in the scope_link section below and are
    # pushed to the firmware.

    # ---- runtime -----------------------------------------------------
    control_rate_hz: 25.0       # nominal only; the loop is depth-frame-driven
    tip_contact_default: false   # value used until the first telemetry message
    start_running: false         # false -> wait for a RUN/RESET on /scope/run_state

    # ================================================================
    # scope_link (serial bridge to the ESP32-S3). Unknown-to-a-node keys
    # in a '/**' block are ignored, so policy_node ignores these and
    # scope_link ignores the policy keys above.
    # ================================================================
    port: "/dev/ttyUSB0"         # CP2102 "UART" jack, forwarded into WSL via usbipd
    baud: 921600
    reconnect_period_s: 1.0
    enable_on_connect: false      # false -> firmware boots in SAFE_HOLD, send ScopeCommand ENABLE

    # Safety governor limits, pushed to the firmware on every connect.
    # These are the tunables -- raise/lower without reflashing.
    current_limit_ma: 800.0       # per-servo present current; over this (debounced) -> SAFE_HOLD
    tension_limit_g: 250.0        # per-cable tension; over this (debounced) -> SAFE_HOLD
    spike_debounce_ms: 20         # how long a spike must persist before it trips
    comms_timeout_ms: 120         # no setpoint for this long -> firmware SAFE_HOLD
    motor_hz: 200                 # servo goal-streaming rate inside the firmware
    telem_hz: 50                  # telemetry report rate

    # Asymmetric per-axis-per-direction bend limits, encoder ticks.
    # Measured 2026-09-09 with `bend <x|z>` (tip free, out of housing) --
    # hardware/bringup/measured_constants.md. Firmware maps the normalised
    # command -1..+1 to ticks with these. +x = pull servo 1, -x = servo 3;
    # +z = pull servo 2, -z = servo 4.
    maxpull_x_pos_ticks: 724      # 63.63 deg
    maxpull_x_neg_ticks: 681      # 59.85 deg
    maxpull_z_pos_ticks: 840      # 73.83 deg
    maxpull_z_neg_ticks: 603      # 53.00 deg
    maxpull_headroom: 0.9         # drive only this fraction (friction in the housing/colon)

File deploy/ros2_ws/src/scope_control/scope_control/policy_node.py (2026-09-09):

"""
policy_node -- the brain of the deployment control loop.

    /scope/depth  (sensor_msgs/Image, 32FC1, 1x54x96, already [0,1])
    /scope/telemetry (scope_msgs/ScopeTelemetry)      -> tip_contact, safety
    /scope/estop  (std_msgs/Bool, latched)            -> freeze
    /scope/run_state (scope_msgs/ScopeRunState, latched) -> RUN / STOP / RESET
                              |
                              v
                        [ policy_node ]
                              |
                              v
    /scope/action (scope_msgs/ScopeAction)  -> absolute tendon pull, mm

The node is FRAME-DRIVEN: one decision per incoming depth frame, not on a timer.
The depth model is the slowest link (~32 ms of the 40 ms budget), so its frame
arrival IS the loop clock. A timer-driven design would either starve or double up
whenever the two rates drift -- exactly the phase-offset trap.

WHAT THIS NODE REPRODUCES FROM THE SIMULATOR (and why here)
----------------------------------------------------------
Five of the six policy state values are software, not sensors, and MUST be
reproduced bit-for-bit or the network sees an observation it was never trained
on (docs/architecture.md, "What is deliberately not observed"):

  state[0:2]  cmd_x_n, cmd_y_n   -- the PD command shaper's own output, normalised
  state[2:5]  last_action[0:3]   -- the previous action the network emitted
  state[5]    tip_contact        -- the ONE real sensor value (from telemetry)

The PD shaper (scope_colon_env.py step(), ~lines 1004-1021) is a 4-scalar
recursive filter whose output is fed straight back into the next observation. It
therefore lives *inside* this loop. Its gains were fitted at 25 Hz and do NOT
rescale arithmetically -- a x4 rescale puts the poles at |z|=1.337 (unstable).
Do not touch PD_KP / PD_KD without re-fitting against the wall-clock step
response (navigation/v9/diagnostics/pd_rate_rescale.py).

The order of operations per frame mirrors the sim exactly:
  env.reset() returns obs with cmd=0, last_action=0            <-> RESET / first frame
  env.step(a) : shaper updates from a, THEN obs is rebuilt     <-> on_depth()
so the observation built at the end of step t carries the shaper state *after*
applying action t, and that is what feeds inference for action t+1.
"""

from __future__ import annotations

import sys

import numpy as np
import rclpy
from rclpy.node import Node
from rclpy.qos import (
    QoSDurabilityPolicy,
    QoSHistoryPolicy,
    QoSProfile,
    QoSReliabilityPolicy,
)
from std_msgs.msg import Bool
from sensor_msgs.msg import Image

from scope_msgs.msg import ScopeAction, ScopeRunState, ScopeTelemetry

from scope_control.policy_runner import MockPolicyRunner, PolicyRunner
from scope_control.shaper import pd_shaper_step


# --- QoS profiles --------------------------------------------------------
# Absolute setpoints / sensor streams that SUPERSEDE: keep only the newest, and
# never let a slow consumer build a stale backlog. This is the fix for the
# "works, then progressively lags" symptom.
SENSOR_QOS = QoSProfile(
    reliability=QoSReliabilityPolicy.BEST_EFFORT,
    history=QoSHistoryPolicy.KEEP_LAST,
    depth=1,
)
# Latched state/events: a late subscriber must still get the last value.
LATCHED_QOS = QoSProfile(
    reliability=QoSReliabilityPolicy.RELIABLE,
    history=QoSHistoryPolicy.KEEP_LAST,
    depth=1,
    durability=QoSDurabilityPolicy.TRANSIENT_LOCAL,
)


class PolicyNode(Node):

    def __init__(self):
        super().__init__("policy_node")

        # ---------------- parameters -----------------------------------
        # Contract with the trained checkpoint. Defaults are the v8_p1 / v9 line.
        self.declare_parameter("experiment", "v8_p1_v1")
        self.declare_parameter("nav_code_dir", "")           # dir with sf_encoder.py
        self.declare_parameter("checkpoint_dir", "")         # checkpoint_p0 folder or a best_*.pth
        self.declare_parameter("checkpoint_root", "")        # dir containing runs_sf/
        self.declare_parameter("device", "cpu")
        self.declare_parameter("mock_policy", False)

        self.declare_parameter("depth_height", 54)
        self.declare_parameter("depth_width", 96)
        self.declare_parameter("state_dim", 6)

        # PD command shaper -- fitted at 25 Hz, DO NOT arithmetically rescale.
        self.declare_parameter("pd_kp", 0.1803)
        self.declare_parameter("pd_kd", 0.0475)

        # NOTE: MAX_PULL is NOT a parameter here. The shaper runs in normalised
        # units (+/-1 = full commanded bend), exactly as the sim's
        # cmd_pair / MAX_PULL: the scale factor cancels out of the observation.
        # The real, asymmetric per-axis-per-direction encoder limits live only
        # in the firmware (pushed via scope_link's CONFIG frame).

        self.declare_parameter("control_rate_hz", 25.0)   # only sizes the stale-frame warning
        self.declare_parameter("tip_contact_default", False)
        self.declare_parameter("start_running", False)

        gp = self.get_parameter
        self._h = int(gp("depth_height").value)
        self._w = int(gp("depth_width").value)
        self._state_dim = int(gp("state_dim").value)
        self._kp = float(gp("pd_kp").value)
        self._kd = float(gp("pd_kd").value)
        self._ctrl_dt = 1.0 / max(float(gp("control_rate_hz").value), 1e-3)
        self._tip_default = bool(gp("tip_contact_default").value)
        self._running = bool(gp("start_running").value)

        if self._state_dim != 6:
            self.get_logger().warn(
                f"state_dim={self._state_dim} (expected 6). The state vector layout "
                "below assumes the 6-D [cmd_x_n, cmd_y_n, last_action[0:3], tip_contact]."
            )
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

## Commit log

2026-08-06 Initial commit: Mujuco_V3 working tree at v8_p1
    Places the live project under version control for the first time. Snapshot of
    the tree as of the completed A-F retrain (v8_p1_v1, 4.52M steps), taken before
    any repository restructuring or documentation rewrite.
    Excluded via .gitignore: model checkpoints (*.pth - da3small_finetune_head.pth
    alone is 131 MB, over GitHub's 100 MB limit; distribute via Releases),
    generated scenes/, TensorBoard .summary/ event files, and __pycache__.
    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
    [control_log.csv, eval_best_000000728_2981888_reward_1.238_eps5_seeds80_20260629_195727.csv, new8.stl]
2026-08-06 Harvest curated portfolio docs, LICENSE and requirements from colonoscope-rl
    Brings across the four hand-written docs that existed only in the v6-era
    portfolio snapshot (architecture, results, domain_randomisation,
    design_iterations) plus its publishing checklist, MIT LICENSE and
    requirements.txt. Nothing in colonoscope-rl was modified or removed.
    The five markdown files land in docs/portfolio/ rather than docs/ and each
    carries a banner marking it as v6_dr-era and superseded by CURRENT_PLAN.md.
    This keeps them from reading as current design docs - the project has already
    been damaged once by parallel documents disagreeing with the plan.
    docs/eval_results.csv was deliberately not copied: i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
2026-08-06 Add docs/architecture.md and the hardware/ skeleton
    architecture.md is the reference doc the README was missing - it previously
    pointed at a dated snapshot for the "how does this work" job. Written for
    v8_p1 from the live code and the control-loop report, not from the v6
    portfolio doc, which was wrong in ways that matter: 64x64 square depth
    (now 54x96 at 16:9), a 10-D state vector (now 6-D), PD gains 0.06/0.30 (now
    0.1803/0.0475, and they do not rescale with control rate), a kinematic base
    (now a physical 44-link shaft on friction rollers), and depth described as
    metric when it is per-frame normalised and scale-relative.
    The superseded portfolio/architecture.md moves to docs/archive/portfol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
2026-08-06 hardware/cad: add destination folders and Pack and Go procedure
    Creates native/ step/ stl/ print/ so the SolidWorks export has a defined
    destination, and replaces the generic move advice with the concrete
    procedure for porting Full assem.SLDASM.
    Records which files in the source folder are superseded iterations (three
    spool variants, three sts3032 bracket variants, and an STL/ folder that is
    print history from 2026-07-24 to 2026-08-05) so they are not carried across
    by mistake. Pack and Go resolves which parts are live; STLs get re-exported
    from the copy rather than copied.
2026-08-06 hardware/cad: cover both top-level assemblies in one Pack and Go
    Full assem and Layout Assembely share parts, and whether the latter is a
    sub-assembly of the former was not established. Using Add File to package
    both in a single operation is correct either way, and avoids the failure
    mode of two separate runs into one folder: colliding files, per-file
    overwrite decisions, and two assemblies left pointing at different copies
    of the same part.
    Also adds Flatten to single folder, since the source tree has Prints/,
    Step/ and STL/ subfolders that need not be reproduced.
2026-08-06 hardware/cad: add Full assem and Layout Assembely via Pack and Go
    10 of 16 source parts plus both top-level assemblies, 2.7 MB. Pack and Go
    resolved which parts are live; the 6 left behind are superseded iterations:
    mg996r and Servo holding block (the design moved to STS3032 serial servos),
    Shaft ring, Spool helic reverse, Spool_testing, and the single sts3032
    Bracket that the male/female pair replaced.
    Copy is independent - the originals in Documents\Solidworks Projects\Endoscope
    are untouched. Every part matches its source byte length; Layout Assembely
    is 0.73 -> 0.37 MB and has not yet been verified by opening.
    STEP and STL exports are still outstanding.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
    [Cantilever bracket.SLDPRT, Full assem.SLDASM, Layout Assembely.SLDASM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]
2026-08-06 hardware/cad: document STL export and the GitHub 3D viewer
    The viewer needs no setup - GitHub renders committed .stl files natively -
    but it does not render inline in a README, which is worth stating so the
    front page still gets a rendered PNG. Records the assembly-STL export
    choice: one combined file for viewing, per-part files for printing.
2026-08-06 hardware/cad: flatten to one folder, add the assembly STL
    Four subfolders for 14 files was overhead with no benefit, and a flat
    directory is also how SolidWorks resolves sibling references with no path
    rewriting. native/ step/ stl/ print/ are gone; everything sits in cad/.
    Adds Full assem.STL (6.6 MB, merged mesh of the whole rig) and links it from
    the top-level README and hardware/README.md - GitHub renders .stl in an
    interactive 3D viewer, so this is the first thing in the repo that shows the
    hardware rather than describing it.
    Per-part print STLs are deliberately not kept: anyone needing print geometry
    can export it from the assembly.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
    [Cantilever bracket.SLDPRT, Full assem.SLDASM, Full assem.STL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]
2026-08-06 hardware/cad: cut the README down to what a viewer needs
    The page had grown into a tutorial - export settings, size limits, Pack and
    Go procedure, superseded-part history - none of which serves someone opening
    it to look at the CAD. Now: what the rig is, the 3D view, which parts are
    bought-in and what was designed around them, and the file list.
    Adds the bought-in note that was missing: sts3032 (serial bus servo) and
    Load cell block (cantilever force bar) are off-the-shelf, and the brackets
    around them exist because of their mounting patterns and load paths.
    The removed procedure is not lost - it moves to docs/DEV_SETUP.md, which is
    where operational how-to belongs.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
2026-08-06 hardware/cad: rotate the assembly STL upright
    The export put the 179 mm length along Z, so the rig showed standing on end
    in the GitHub viewer. Rotated 90 degrees about X: the base plane is now
    179 x 129 mm with 109 mm of height, which is how the rig actually sits.
    Mesh rotated directly rather than re-exported - vertices and facet normals
    both transformed, triangle count unchanged at 138,262. A permanent fix
    belongs at export time via Output coordinate system in the STL options.
    [Full assem.STL]
2026-08-06 hardware/cad: add renders, cable-path note, and the bought-in bearing
    Three views added (isometric, side profile, top). The green lines in the
    side and top views are drawn cable paths - construction geometry, not parts -
    which is worth stating since they read as hardware otherwise.
    Records that the shaft clamp is designed for a 9-10 mm OD shaft with four
    antagonistic tendon cables, matching the simulated scope, and adds the
    bearing to the bought-in list alongside the STS3032 servo and the load cell.
    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
2026-08-06 Add perception/README.md
    perception/ was the only top-level folder without a front page - a reader
    following the repo map landed on a bare list of .py files. Mirrors the
    structure of navigation/README.md: what the two subfolders are, what the
    pipeline produces, which script does what, and the known gaps.
    States the relative-not-metric caveat prominently, since 1.43 mm reads as a
    deployable distance accuracy and is not one, and notes that documents quoting
    1.60 mm are wrong.
2026-08-31 README: lead with the closed-loop demo; correct navigation/README to the 2026-08-04 retrain
    - Embed a 33s H.264 clip of the full perception+policy loop at the top of the
    README (transcoded from the un-playable MPEG-4 Part 2 original).
    - navigation/README.md: v8_p1 is the A-F retrain (~97% mean progress, training
    stat, no eval), state is 6-D with no force/cable channel, 25 Hz, 16:9 cam
    - was still describing the 2026-07-13 8-D / 93.5% run.
    Claude-Session: https://claude.ai/code/session_01LfuSNkbad2eknW8qfE5hEk
2026-08-31 README: use an inline GIF for the demo (repo is private, <video> raw-URL won't render)
    A <video> tag pointing at a raw URL only plays for public repos. Embed a
    512px GIF of the full 33s run instead, linked to the H.264 mp4 for the
    full-resolution version. Swap back to a player via a user-attachments
    upload if/when the repo goes public.
    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
2026-08-31 hardware: add the flex tip-contact sensor PCB
    New hardware/electronics/ with flex_tip_sensor/ — KiCad 10 project + Gerbers
    for the single-layer polyimide flex electrode that provides the binary
    tip_contact signal (interdigitated comb + piezoresistive film, wraps the
    9mm tip disk). Fabricated, not yet calibrated or wired in — WIP.
    Updates hardware/README.md (folder table, Contact requirement, Status) and
    the top-level repo map, which described the tip-contact sensor only as a
    requirement.
    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
    [flex tip sensor.kicad_pcb, flex tip sensor.kicad_sch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]
2026-08-31 hardware: add tip build photo, flex-sensor layout, tip-to-shaft clip
    - flex_tip_sensor/README: real build photo + KiCad layout image, replacing
    the photo placeholder.
    - hardware/README: lead with the tip build photo; link an 8 s audio-free
    clip of the tip-to-shaft internals (spring and braided housing removed).
    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
2026-08-31 hardware/README: lead with a work-in-progress note; add feed + PCB detail
    - Top callout: rig is WIP, nothing trialled, insertion hand-fed, first tests
    run without the feed drive to isolate the steering response.
    - Feed requirement row notes a[2] is a hand-feed cue for now, not a driven axis.
    - Show the flex-sensor PCB layout in the Status section.
    - Replace the broken tip-to-shaft video link with a marked spot to upload it.
    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
2026-08-31 Revise README with updated internals description
    Updated the description of the tip-to-shaft internals and added an image.
2026-08-31 hardware/README: cross-section beside the internals clip; fix tip photo caption
    - Put the shaft cross-section diagram next to the tip-to-shaft clip in a
    two-cell table, each at natural aspect.
    - Correct the tip build photo caption: the orange ribbon is the camera
    cable, not the flex sensor (which is not in that shot).
    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
2026-08-31 docs/media: drop the orphaned demo files
    closedloop_nav_demo.gif / .mp4 and tip_to_shaft_internals.mp4 are no longer
    referenced — the README demo and the hardware clip both moved to GitHub
    user-attachments uploads. docs/media/ is v1-era recorded runs again.
    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
2026-08-31 docs: archive the 2026-08-05 control-loop report
    It was a dated progress report, linked from the front page as reference —
    588 dense lines restating architecture.md. Moved to docs/archive/ with a
    banner; salvaged first:
    - hardware/README.md: a compact "constants the deployment loop must
    reproduce" table (rate, obs shapes, MAX_PULL, PD gains, force rail, etc.).
    - hardware/bringup/README.md: the full camera-roll-offset analysis (sim
    convention table, why a non-90° offset can't be fixed in the action,
    the state-echo frame trap).
    Dropped all four inbound links (README, docs/README, architecture.md,
    hardware/README). architecture.md + hardware/README.md now cover the loop.
    Co-Authored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
2026-08-31 CURRENT_PLAN: de-alarm the roller feeder; future phase is rig-results-driven
    - §8: the "roller feeder stalls at slow insertion" bullet was a red ⚠️
    implying the sim can't represent the intended deployment. Reworded: the
    feeder works at the trained 30 mm/s; the slow-feed stall only matters for
    slow-feed training, which isn't planned. Same reword in hardware/bringup.
    - §7: first rig trials are hand-fed, steering-focused (feed drive not built).
    - §9: the next phase is scoped from the physical-test results, not a
    committed Phase 2; gravity + anatomical colon kept as the likely content.
    - Header: bump date, fix a §9→§10 cross-ref.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
2026-09-06 README: add work-in-progress note under the tagline
    Flags the project as actively changing and points to CURRENT_PLAN.md for
    current status.
    Claude-Session: https://claude.ai/code/session_01WAHAMSRLcNdgoNYTZHUGU6
2026-09-09 deploy: add the physical-rig control loop (ROS 2 + Windows vision + ESP32-S3 firmware)
    End-to-end runtime stack for the trained policy: camera -> DA3 depth -> APPO
    policy -> tendon setpoints -> ESP32-S3. Training/simulation stays in navigation/.
    ROS 2 graph (deploy/ros2_ws/, WSL2 Humble):
    - scope_msgs: ScopeAction (abs pull mm per antagonistic pair), ScopeTelemetry
    (servo-ID-indexed arrays), ScopeRunState, ScopeCommand.
    - policy_node: frame-driven inference. Reproduces the sim's PD command shaper
    (fitted gains, not rescalable) and previous-action echo exactly -- they are
    policy inputs. Deterministic mean; GRU state zeroed only on RESET. Publishes
    absolute pull in mm so calibration s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
    [depth_bridge.py, fake_depth_pub.py, mock_firmware.py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]
2026-09-09 deploy: normalise the steering command; asymmetric MAX_PULL moves into firmware
    The `bend` calibration (2026-09-09) showed the two directions of each tendon
    axis are asymmetric -- mildly on X (724 vs 681 ticks), strongly on Z
    (840 vs 603). Sim's MAX_PULL is one symmetric value per axis and the policy
    trained on that, so the observation must stay symmetric while the asymmetry is
    absorbed at the encoder-tick layer.
    - ScopeAction now carries cmd_x_n / cmd_y_n in [-1, 1] (was mm). policy_node's
    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
